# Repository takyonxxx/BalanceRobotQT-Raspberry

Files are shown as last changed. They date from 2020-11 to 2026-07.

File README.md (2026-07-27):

# Balance Robot — Pi 5 + iOS Remote (BLE)

A two-wheeled self-balancing robot. Qt/C++ control application on Raspberry Pi 5, with an iOS BLE remote control featuring a **PID auto-tune (learning) mode** and a **Claude voice assistant** (speak to the robot, Claude drives it).

<p align="center">
    <a href="https://github.com/takyonxxx/BalanceRobotQT-Raspberry/blob/master/remote_ios.jpg">
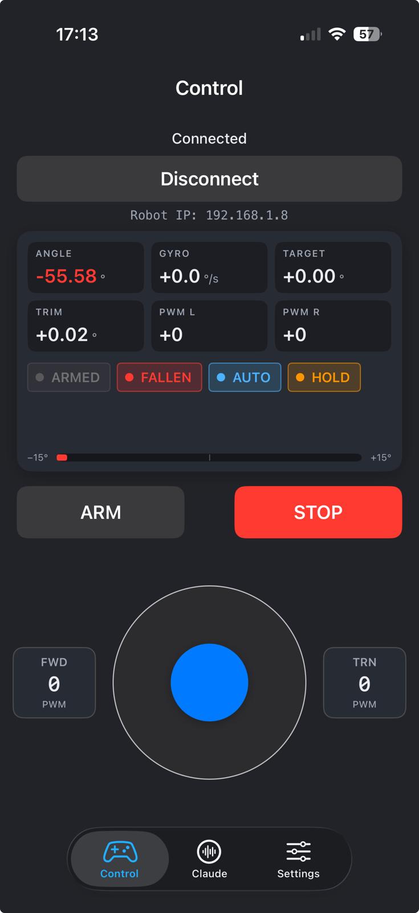
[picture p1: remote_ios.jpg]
iOS Remote
        
    </a>
</p>

## Demo video

See the robot in action: [Balance Robot — YouTube](https://www.youtube.com/watch?v=qpsppoBpccU)

## Architecture

```
iOS Joystick ──BLE GATT──> Pi 5 (Qt/C++) ──> Motor Driver
                              ↑                    ↓
                           MPU6050              Encoders
                          (IMU @ I2C)          (Quadrature)
```

**Control architecture — B-Robot style cascaded PID:**

```
joystick ──> Speed PID ──> target tilt ──> Pitch PID ──> motor PWM
              (outer)                       (inner)
                ↑                              ↑
            encoder vel                  IMU angle + gyro
```

- **Speed PID (outer loop):** Computes the correct body tilt to track the target velocity. When the stick is released, it leans the opposite way to **brake automatically**.
- **Pitch PID (inner loop):** Generates motor PWM to chase the target angle and keep the robot upright.

## Parameters

All parameters can be tuned live from the iOS Settings tab and are persisted to `settings.ini` on the Pi.

### Pitch PID — Balance (inner loop)

| Parameter | Default | Description |
|---|---|---|
| P (Proportional) | 25 | Instant response to angle error. High = stiff correction, oscillation risk. |
| I (Integral) | 40 (0.40 real) | Corrects persistent angle error (gravity bias). |
| D (Derivative) | 0.10 | Angle rate of change — damping. High = reduces swinging. |
| Angle trim (AC) | 0.0° | Manual angle offset. |
| Yaw gain (SD) | 2.0 | Heading correction from encoder difference. |

### Speed PID — Velocity control (outer loop)

| Parameter | Default | Description |
|---|---|---|
| Speed Kp | 0.12 | Instant response to velocity error. High = agile but oscillates. |
| Speed Ki | 0.20 | Integrates velocity error — the workhorse of the Speed PID. |
| Speed Max Tilt | 5° | Maximum tilt angle the Speed PID can request. |
| Speed Max Vel | 3.0 | Target velocity at full stick deflection (encoder ticks/loop). |

### iOS-only

| Parameter | Default | Description |
|---|---|---|
| Forward speed | 180 | Max byte value (0-255) sent for forward/back joystick. |
| Turn speed | 60 | Max byte value sent for left/right joystick. |

## Tuning guide

### For snappier response
1. First raise **Speed Max Vel** (3.0 → 4.0 → 5.0) — increases target velocity ceiling
2. Then raise **Speed Kp** (0.12 → 0.15 → 0.18) — more agile response
3. If still not enough, raise **Speed Max Tilt** (5° → 6° → 7°) — more aggressive acceleration

### Symptoms and fixes
- **Long coast after stick release** → raise Speed Ki (0.20 → 0.30)
- **Oscillating / jittery** → lower Speed Kp
- **Swings back and falls after release** → lower Speed Ki
- **Drifts in place, won't sit still** → raise Pitch Ki
- **High-frequency vibration** → raise Pitch Kd
- **Front-to-back wobble during startup** → lower Pitch Kp

### Reset to Defaults
At the bottom of the iOS Settings tab, the red **"Reset all settings to defaults"** button restores every PID parameter to the Pi-side defaults.

## PID auto-tune — learning mode

Instead of tuning the Pitch PID by hand, the robot can tune itself. The Pi runs a **Twiddle (coordinate-descent) auto-tuner** that evaluates candidate `[Kp, Kd, Ki]` sets live while the robot balances, and commits the best set to `settings.ini` when done.

**How it works:**

1. Each candidate is evaluated for ~9 s (2 s settle + 7 s measure).
2. During measurement each candidate is exercised with a **gentle real maneuver script** through the same command channels the joystick and voice use: 0.8 s forward at command 60/180 then CUT (brake transient measured), 0.8 s backward then cut, 0.5 s left turn at 20/60, 0.5 s right turn, then idle recovery. Long recovery gaps separate the maneuvers. Intensity is tunable in `settings.ini` root: `learnMoveCmd=60`, `learnTurnCmd=20` — lower them if the robot still falls during evals. The cost window includes the moments right after each cut, so the tuner directly rewards "come back to balance as fast as possible after *dur*".
3. Cost = angle-error² + gyro-rate² + PWM² (weighted) → tracking accuracy, oscillation and motor chatter are all penalized together.
4. Twiddle shrinks/grows the search deltas per gain; the run converges typically in 3–6 minutes (hard cap: 40 evaluations, ~7 min with maneuvers).

**Safety & fall recovery:** a fall during an evaluation is detected (maneuver commands are zeroed immediately), that candidate gets infinite cost and gains revert to the best known set. The run then **waits for you**: stand the robot upright, auto-arm kicks in, and learning resumes with a fresh candidate from where it left off — the robot even tells you so ("Beni dik konuma getirirsen öğrenmeye kaldığım yerden devam ederim"). Five falls abort the whole run (best-so-far kept). Touching the joystick restarts only the current candidate's measurement; the tuner's own scripted maneuvers do NOT count as user input.

**How to start it:**

- iOS **Settings tab → "PID LEARNING (AUTO-TUNE)" card → Start**. Live status lines from the Pi (baseline cost, per-evaluation results, best gains found) stream into the card.
- Or by voice, from the **Claude tab**: *"PID öğrenmeyi başlat"* / *"start PID learning"*.

**Ground rules:** run it on a hard, flat floor with ~1 m of clear space around the robot — it wobbles on purpose. The robot must already be able to balance on its own before you start. Only the Pitch PID (inner loop) is optimized; Speed PID stays on the sliders.

## Claude voice assistant (iOS)

The third tab, **Claude**, turns the phone into a voice interface for the robot. Tap the mic, speak (Turkish or English), and Claude answers out loud — and can actually drive the robot through tool calls.

```
Mic ──> SFSpeechRecognizer (tr-TR) ──> Anthropic Messages API ──> tool calls ──> BLE commands
                                              │
                                              └──> reply text ──> AVSpeechSynthesizer (spoken)
```

**Tools Claude can use:**

| Tool | What it does |
|---|---|
| `move_robot` | forward / backward / left / right, speed 10–100 %, duration 0.3–5 s (auto-stops when the duration ends) |
| `stop_robot` | zero all motion commands immediately |
| `set_armed` | ARM / DISARM |
| `start_pid_learning` / `stop_pid_learning` | PID auto-tune control |
| `get_robot_status` | reads live telemetry (angle, PWM, armed / fallen / learning flags) |
| `reset_trim` | zero the trim integrator |

Example voice commands: *"ileri git"*, *"iki saniye sağa dön"*, *"dur"*, *"PID öğrenmeyi başlat"*, *"robot nasıl, denge durumu ne?"*, *"motorları kapat"*.

**Setup — API key only, no username/password:**

**Free offline mode (no API, no cost):** if no API key is entered, the Claude tab automatically falls back to an **on-device keyword parser** (`LocalCommandParser.swift`). All robot voice commands — move, stop, arm/disarm, PID learning, status, trim — work **completely free and offline** (speech recognition itself is Apple's, also free). What you lose without an API key is only the conversational part: free-form questions, multi-step reasoning, and natural phrasing ("take it easy and go a bit forward"). Commands must roughly match the keywords (*ileri, geri, sola, sağa, dur, durum, PID öğrenmeyi başlat, trim sıfırla, motorları kapat* — with optional "*iki saniye*" duration and "*hızlı/yavaş/%60*" speed modifiers).

If you do want full conversational Claude: the assistant talks directly to the Anthropic API. There is **no login, no username, no password anywhere** — the only credential is an **API key** (pay-per-use, separate from any Claude subscription):

1. Create a key at [console.anthropic.com](https://console.anthropic.com) → **API Keys** (the key starts with `sk-ant-`). This is tied to your Anthropic account and billing; the app itself never asks you to sign in.
2. In the app, open the **Claude** tab and tap the **key (🔑) button**, paste the key. It is stored on-device in `UserDefaults` and sent only in the `x-api-key` header of API requests.
3. On first mic use, iOS will ask for **Microphone** and **Speech Recognition** permissions — both must be granted (usage descriptions are already in `Info.plist`).

Default model is `claude-sonnet-4-6` (`AppSettings.claudeModel`). The **speak replies** switch on the tab toggles text-to-speech; typing in the text field works as an alternative to the mic.

**Free cloud alternative — Google Gemini (free quota):** full conversational assistant without paying, using Gemini's free API tier:

1. Go to [aistudio.google.com/apikey](https://aistudio.google.com/apikey), sign in with any Google account and create an API key (starts with `AIza`). **No credit card required** — the free tier gives a daily request quota that is plenty for hobby use.
2. In the app, tap the **key (🔑) button** on the Claude tab → **"Gemini anahtarı gir (ücretsiz)"**, paste the key.
3. Done — the same voice pipeline, tools and robot commands now run through Gemini (`GeminiService.swift`, default model `gemini-2.0-flash`).

Provider priority is automatic: **Claude key → Gemini key → offline parser**. If both keys are set, Claude is used; delete keys from the same 🔑 menu to fall back. If the Gemini free quota runs out for the day (HTTP 429), the app tells you to wait — or just use the offline command mode, which never runs out.

## Direction convention

- **Joystick up** = forward
- **Joystick down** = backward
- **Joystick left/right** = turn
- On the Pi: `cmd > 0` means forward, `cmd < 0` means backward
- Encoder positive direction = robot's forward direction

`ControlViewController.swift:41` has `invertY = false` to enforce this. If your motors are wired in reverse, flip it to `true`.

## BLE protocol — Message IDs

`message.h` (Pi) and `MessageService.swift` (iOS) must match.

```
mHeader        = 0xb0  // Packet header
mWrite         = 0x01  // Write request
mRead          = 0x02  // Read request
mArmed         = 0x03  // ARM robot
mDisArmed      = 0x04  // DISARM robot
mForward       = 0xa0  // Forward command
mBackward      = 0xa1  // Backward command
mLeft          = 0xb0  // Turn left
mRight         = 0xb1  // Turn right
mPP            = 0xc0  // Pitch Kp
mPI            = 0xc1  // Pitch Ki
mPD            = 0xc2  // Pitch Kd
mSpdKp         = 0xc3  // Speed Kp (value/100)
mSpdKi         = 0xc4  // Speed Ki (value/100)
mSpdMaxTilt    = 0xc5  // Speed Max Tilt (raw degrees)
mSpdMaxVel     = 0xc6  // Speed Max Vel (value/10)
mAC            = 0xd0  // Angle trim (value/10)
mSD            = 0xd1  // Yaw gain (value/10)
mData          = 0xe1  // Pi → Phone IP / diagnostics text
mTelemetry     = 0xf0  // Live telemetry stream
mAutoMode      = 0xf1  // Auto-arm on/off
mTrimFine      = 0xf2  // Fine trim
mPositionHold  = 0xf3  // Position hold
mResetTrim     = 0xf4  // Reset trim
mPidLearn      = 0xf5  // PID auto-tune: write 1=start 0=stop, read=state
mPidStatus     = 0xf6  // Pi -> Phone: PID learn status text (UTF-8)
```

> `0xe0` is reserved (formerly `mSpeak` / on-board TTS, removed in the cleanup pass).

Telemetry flags byte (packet byte 12): bit0 = armed, bit1 = fallen, bit2 = auto-mode, bit3 = position-hold, **bit4 = PID learning active**.

## Voice assistant on the Pi — phone-free operation

The robot can also listen and act **entirely on its own**: a USB microphone on the Pi, offline Turkish speech recognition, and the same command/LLM pipeline as the iOS app — working even when the mobile app is closed. Main control lives on the Pi; the phone becomes optional.

```
USB mic ──> arecord ──> Vosk (offline TR STT) ──> intent router
                                                     │
                                     ┌───────────────┴───────────────┐
                                     │ command?                       │ question?
                                     ▼                                ▼
                          local keyword parser              Gemini (free) / Claude API
                          (ileri/geri/dur/PID/durum)        with the same robot tools
                                     │                                │
                                     └────────────┬───────────────────┘
                                                  ▼
                                   RobotControl (atomic, thread-safe)
                                                  +
                                   Piper TTS ────────> speaker
```

**How commands vs questions are separated:** every recognized utterance first goes through the local keyword parser (same vocabulary as the iOS offline mode). If it matches a robot command it executes immediately — offline, free, low latency. Anything that doesn't match is treated as a question and forwarded to the LLM (Gemini free tier or Claude, whichever key is set in `settings.ini`), which can still drive the robot through the same 7 tools. No key set → commands still work, questions get a spoken "komutları söyle" hint.

**Wake word:** by default the robot only reacts to utterances containing "robot" ("robot ileri git"). After the wake word it keeps listening for 10 s so follow-ups don't need it. Set `wakeWord=` (empty) in `settings.ini` to react to everything.

**Language — speak TURKISH to the Pi:** the bundled speech model (`vosk-model-small-tr`) understands **Turkish only**. English keywords exist in the parser for completeness, but the Turkish acoustic model will not transcribe spoken English reliably — so on the Pi, use Turkish. (The iOS app is different: Apple's recognizer handles both TR and EN.) To make the Pi English-speaking instead, download `vosk-model-small-en-us-0.15` and point `voskModelPath` at it.

**Voice command reference (Pi) — complete list.** Say the wake word first — *"robot …"*. After any command a 10-second attention window opens: follow-ups don't need the wake word. Saying just *"robot"* gets *"Evet, dinliyorum"* and opens the window. Word order inside the sentence doesn't matter.

| Amaç | Tetikleyici kelimeler (herhangi biri yeter) | Örnek |
|---|---|---|
| **İleri** | ileri, öne, forward | *"robot ileri git"* |
| **Geri** | geri, arkaya, back | *"robot geri git"* |
| **Sola dön** | sol, sola, left (tam kelime) | *"robot sola dön"* (varsayılan %50, 1 sn) |
| **Sağa dön** | sağ, sağa, right (tam kelime) | *"robot sağa dön"* (varsayılan %50, 1 sn) |
| **Dur** | dur, stop, kes, bekle | *"dur"* (pencere içinde "robot" gerekmez) |
| **Kendini tanıt** | tanıt, tanımla, kimsin, kendini | *"robot kendini tanıt"* — tasarımcısı dahil kısa tanıtım okur |
| **Durum oku** | durum, nasıl, status, telemetri, açı, denge | *"robot durum ne"*, *"robot nasılsın"* |
| **PID öğrenme başlat** | pid/öğren/learn + başlat, başla, start, aç | *"robot PID öğrenmeyi başlat"* |
| **PID öğrenme durdur** | pid/öğren/learn + durdur, bitir, iptal, stop, kapat | *"robot PID öğrenmeyi durdur"* |
| **Trim sıfırla** | trim + sıfırla, resetle, reset, temizle | *"robot trim sıfırla"* |
| **Motorları kapat (disarm)** | disarm, motorları kapat, motoru kapat, devre dışı | *"robot motorları kapat"* |
| **Motorları aç (arm)** | arm, hazırlan, dengele, motorları aç, motoru aç | *"robot motorları aç"* |
| **Serbest soru** (API anahtarı gerekir) | yukarıdakilerle eşleşmeyen her şey | *"robot neden devriliyorsun?"* |

**Hareket komutlarına eklenebilen niteleyiciler** (ileri/geri/sola/sağa ile birlikte, sırası önemsiz):

| Niteleyici | Söyleyiş | Etki |
|---|---|---|
| Hız — kelimeyle | yavaş / nazik → %30 · hızlı → %75 · çok hızlı → %90 · tam gaz / full → %100 | *"robot yavaş ileri git"* |
| Hız — yüzdeyle | "yüzde" + sayı (on…doksan, yüz veya rakam), %10–100 | *"robot yüzde altmış ileri git"* |
| Süre | sayı + "saniye" (yarım, buçuk, bir…on veya rakam), 0.3–8 sn | *"robot üç saniye geri git"* |
| Birleşik | hız + süre aynı cümlede | *"robot yüzde kırk iki saniye sola dön"* |

Varsayılanlar (niteleyici söylenmezse): ileri/geri **%100 / 1.5 sn**, dönüşler **%50 / 1 sn** (`settings.ini` → `moveDefaultPct` / `turnDefaultPct` / `moveDefaultSecs`). Hareket süre sonunda otomatik durur; *"dur"* her an keser.

The rows above are matched **offline by the local parser** — free, instant, no internet. Only free-form questions need an API key.

**New files:** `voiceassistant.cpp/.h` (mic capture, Vosk STT via `dlopen`, intent routing, TTS queue), `llmclient.cpp/.h` (Gemini + Claude REST clients with the tool loop, Qt-native). `libvosk` is loaded at **runtime** — it is *not* a build dependency, so the firmware builds and runs unchanged if voice components aren't installed.

### Setup

```bash
# 1. Audio tools + TTS
sudo apt-get install alsa-utils

# 2. Vosk library (prebuilt aarch64, ~2 MB)
cd /tmp
wget https://github.com/alphacep/vosk-api/releases/download/v0.3.45/vosk-linux-aarch64-0.3.45.zip
unzip vosk-linux-aarch64-0.3.45.zip
sudo cp vosk-linux-aarch64-0.3.45/libvosk.so /usr/local/lib/
sudo ldconfig

# 3. Turkish speech model (~45 MB, runs real-time on one Pi 5 core)
cd ~/BalanceRobotPI
wget https://alphacephei.com/vosk/models/vosk-model-small-tr-0.3.zip
unzip vosk-model-small-tr-0.3.zip

# 4. Microphone: the WEBCAM'S BUILT-IN MIC works - no separate mic needed.
#    The camera streaming service only holds the VIDEO device (v4l2), so the
#    same webcam's audio capture is free to use concurrently.
#    micDevice=auto scans `arecord -l` and picks the USB/webcam mic itself;
#    to check manually:
arecord -l          # e.g. "card 1: Device [USB Audio Device], device 0" -> plughw:1,0
arecord -D plughw:1,0 -f S16_LE -r 16000 -c 1 -d 3 test.wav && aplay test.wav   # 3 s mic test

# 5. settings.ini ([assistant] section, created on first run - voice is
#    ENABLED BY DEFAULT; set enabled=false to turn it off):
#    enabled=true
#    micDevice=auto              ; or plughw:1,0 to pin a specific card
#    voskModelPath=/home/pi/BalanceRobotPI/vosk-model-small-tr-0.3
#    wakeWord=robot
#    geminiApiKey=AIza...        ; optional - free quota, for questions
#    claudeApiKey=               ; optional - takes priority if set
#    piperModel=                 ; optional - path to a Piper .onnx voice (pick a female one, e.g. tr_TR-dfki-medium) for natural TTS
#    moveDefaultPct=100          ; voice move speed %% when not specified (10-100)
#    moveDefaultSecs=1.5         ; voice move duration when not specified (0.5-8 s)
#    turnDefaultPct=50           ; default turn speed %% (100%% turns tip the robot)
#    turnDefaultSecs=1.0         ; default turn duration (fwd/back keep moveDefaultSecs)
#    voiceMaxVel=6.0             ; TEMP speed ceiling for voice fwd/back moves
#                                ; (ticks/loop; joystick keeps its own spdMaxVel;
#                                ;  released when the move stops; 0=disable)
#
# Feeling sluggish even at 100%? The speed cascade is deliberately gentle.
# Three knobs (root section of settings.ini, shared with the joystick):
#    spdTiltSlew=0.04   ; accel ramp, deg/loop (0.02=4°/s gentle, 0.06=12°/s brisk)
#    spdMaxVel=5.0      ; top speed target, encoder ticks/loop (default)
#    spdKi=0.45         ; speed integral (default; spdKp=0.25 for instant response)
# Raise ONE at a time and retest; too much of any can reintroduce tip-overs.

# 6. Restart the app; look for:  VoiceAssistant: listening on plughw:1,0 (wake word: "robot")
```

**Bluetooth speaker (e.g. JBL) for the robot's voice:** replies can play through a BT speaker, managed entirely from `settings.ini`. The stack is **BlueALSA** (not PulseAudio/PipeWire) because the app runs as root and needs a system-level ALSA path.

```bash
# One-time setup
sudo apt-get install bluez-alsa-utils

# Verify the BlueALSA daemon supports playback (a2dp-source):
systemctl status bluealsa    # if OPTIONS lack a2dp-source: edit /etc/default/bluez-alsa
                             # -> OPTIONS="-p a2dp-source"  then: sudo systemctl restart bluealsa

```

**Pairing walkthrough (one-time, from scratch):**

1. Stop the robot app first if it's running (Ctrl+C) — its 30-second auto-connect
   attempts can interfere with pairing.
2. Put the speaker in **pairing mode**: on the JBL Clip 4, with the speaker ON,
   press the **Bluetooth button** (next to power) once — the LED starts
   **blinking blue**. Solid LED = it's connected to another device (e.g. your
   phone): turn that device's Bluetooth off first, then press the BT button.
3. SSH into the Pi and enter the Bluetooth shell — the prompt changes to
   `[bluetooth]#`:

```bash
ssh pi@192.168.1.8
bluetoothctl
```

4. Inside `[bluetooth]#` run, in order (Tab completes the MAC after a few chars):

```
power on
default-agent
scan on                        # wait until "JBL Clip 4" appears with its MAC
pair F8:5C:7D:82:CE:9B         # expect: Pairing successful
trust F8:5C:7D:82:CE:9B        # IMPORTANT - enables automatic reconnection
connect F8:5C:7D:82:CE:9B      # expect: Connection successful + tone from JBL
scan off
quit
```

5. Quick audio test back in the normal shell:

```bash
aplay -D bluealsa:DEV=F8:5C:7D:82:CE:9B,PROFILE=a2dp /usr/share/sounds/alsa/Front_Center.wav
```

**Pairing troubleshooting:**

| Error | Cause | Fix |
|---|---|---|
| `AuthenticationFailed` | Speaker not in pairing mode / connected to your phone | Phone BT off → JBL BT button (blinking blue) → retry `pair` |
| `AlreadyExists` | Stale half-pairing record | `remove F8:5C:7D:82:CE:9B`, then `pair` again |
| `not available` | Dropped from scan list | `scan on`, retry `pair` as soon as it reappears |
| `ConnectionAttemptFailed` | Range/timing | Move JBL closer, press BT button, retry |
| Paired but no sound | Audio path issue, not pairing | Continue with the `bluez-alsa-utils` / `aplay` test above |
| `Couldn't get BlueALSA PCM: PCM not found` + `Device not available: .../sep1/fd0` in `journalctl -u bluealsa` | **PipeWire/WirePlumber grabs the BT stream** before BlueALSA (default on RPi OS Bookworm) | Disable PipeWire's Bluetooth module, then reconnect — see below |

**PipeWire conflict fix (RPi OS Bookworm, one-time):** bluetoothctl reports `Connection successful` yet BlueALSA playback fails, because the desktop audio stack owns the A2DP endpoint. Hand Bluetooth audio to BlueALSA (other audio is unaffected):

```bash
mkdir -p ~/.config/wireplumber/bluetooth.lua.d
echo 'bluez_monitor.enabled = false' > ~/.config/wireplumber/bluetooth.lua.d/80-disable-bluez.lua
systemctl --user restart wireplumber

bluetoothctl disconnect F8:5C:7D:82:CE:9B && sleep 2 && bluetoothctl connect F8:5C:7D:82:CE:9B
aplay -D bluealsa:DEV=F8:5C:7D:82:CE:9B,PROFILE=a2dp /usr/share/sounds/alsa/Front_Center.wav   # should play
```

The change is persistent across reboots. (On headless/Lite images without PipeWire, `systemctl --user` may fail — then a plain disconnect/reconnect usually suffices.)

Pairing is **persistent** (stored under `/var/lib/bluetooth/`): it survives reboots and is never repeated in daily use. Day-to-day you only power the JBL on — the app's auto-connect (every 30 s) does the rest.

Then in `settings.ini` `[assistant]`:

```ini
btSpeakerMac=F8:5C:7D:82:CE:9B   ; default: Türkay's JBL Clip 4; empty = no BT speaker
speakerDevice=                   ; optional ALSA device override; empty = auto
                                 ; (bluealsa:DEV=<MAC>,PROFILE=a2dp built from the MAC)
```

Behavior: on startup the assistant runs `bluetoothctl connect <MAC>` and retries every 30 s, so power-cycling the JBL just works. If a reply fails to play on the BT device (speaker off / out of range), the same sentence is **automatically repeated on the default output** (3.5 mm/HDMI) and reconnection is triggered — the robot never goes silent. Expect ~0.2–0.5 s of extra latency on BT audio; the microphone path (webcam) is unaffected.

**Voice output — Piper (the only TTS engine):** natural offline Turkish voice (`tr_TR-dfki-medium`). Install once; the firmware auto-detects the model file. Without the model+binary, replies are simply not spoken (a log line says so) — everything else keeps working. install [Piper](https://github.com/rhasspy/piper) once; the firmware **auto-detects** the model file and switches to it, no settings change needed:

```bash
# 1. Piper binary (aarch64)
cd /tmp
wget https://github.com/rhasspy/piper/releases/download/2023.11.14-2/piper_linux_aarch64.tar.gz
sudo tar -xzf piper_linux_aarch64.tar.gz -C /opt
sudo ln -s /opt/piper/piper /usr/local/bin/piper

# 2. Turkish female voice model (~60 MB) into the app folder
cd ~/BalanceRobotPI
wget https://huggingface.co/rhasspy/piper-voices/resolve/main/tr/tr_TR/dfki/medium/tr_TR-dfki-medium.onnx
wget https://huggingface.co/rhasspy/piper-voices/resolve/main/tr/tr_TR/dfki/medium/tr_TR-dfki-medium.onnx.json

# 3. Test it
echo "Merhaba, ben denge robotu." | piper -m tr_TR-dfki-medium.onnx --output_raw | \
  aplay -q -r 22050 -f S16_LE -t raw -c 1 -D bluealsa:DEV=F8:5C:7D:82:CE:9B,PROFILE=a2dp
```

Restart the app — replies now use the natural female voice (adds ~0.5 s per sentence on the Pi 5). Reply wording is intentionally SHORT: qualifiers (duration/speed) are spoken back **only if you said them** — *"sola dön"* → *"Sola dönüyorum."*, *"1 saniye sola dön"* → *"Sola dönüyorum, 1 saniye."*

**CPU budget:** the assistant thread runs at low priority; Vosk small uses well under one core. Combined with the camera stream, prefer 640×480 video or disable the camera during PID auto-tune — same guidance as before, the 200 Hz balance loop always has priority.

**Coexistence with the app:** BLE and voice use the same atomic `RobotControl` interface, so both can be active at once. Voice `move` commands auto-stop after their duration; touching the phone joystick simply overrides them.

## Hardware

### Bill of materials

| Part | Specification |
|---|---|
| **Main controller** | Raspberry Pi 5 (Qt/C++ + WiringPi, `wiringPiSetupPhys()`) |
| **IMU** | MPU6050 — 6-axis (3-axis accel + 3-axis gyro), I²C bus 1, address `0x68`. Fused through a Kalman filter to recover pitch angle. |
| **Motor driver** | Waveshare RPi Motor Driver Board — dual H-bridge HAT, **2× NXP MC33886** (one chip per motor) |
| **Drive motors** | 2× 37 mm geared DC motor with Hall quadrature encoder, ~100 RPM @ 4.5 V / ~200 RPM @ 9 V |
| **Battery** | 3S LiPo — 11.1 V nominal (12.6 V full, 9.9 V suggested cut-off), 4000 mAh, 20C+ discharge |
| **Camera (optional)** | Generic UVC USB webcam — MJPEG 1280×720 @ 30 fps, streamed as RTSP H.264 via GStreamer + MediaMTX |
| **Chassis** | 190 mm aluminium balance-bot plate, 3 mm acrylic top, 65 mm × 26 mm rubber tires on electroplated plastic hubs, ~520 g bare |

### Motor driver — Waveshare RPi Motor Driver Board

<p align="center">
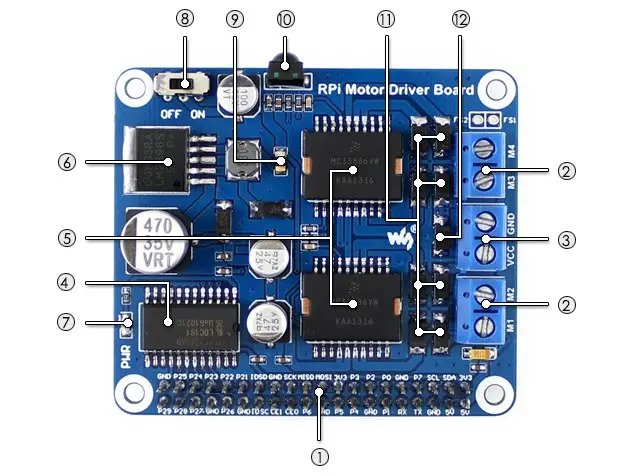
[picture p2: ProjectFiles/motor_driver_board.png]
Waveshare RPi Motor Driver Board — labeled callouts
  
</p>

**Callouts on the photo above:**

| # | Part | Role |
|---|---|---|
| **1** | Raspberry Pi GPIO interface (40-pin header) | Mates with the Pi's header — this is how the six motor-control lines (`PWMR1/PWMR/PWMR2/PWML1/PWML/PWML2`) reach the driver. |
| **2** | Motor screw terminals (M1 A/B, M2 A/B) | Where the two DC motors connect. M1 = right motor, M2 = left motor in this project. |
| **3** | External power input (VIN, GND) | The 3S LiPo (11.1 V) wires land here. 7–40 V accepted. |
| **4** | 74LVC4245AD level-shifter | Voltage translator between the Pi's 3.3 V GPIOs and the H-bridge logic. Acts as a buffer too — protects the Pi. |
| **5** | MC33886 H-bridge × 2 | The actual motor drivers. One chip per motor, up to 5 A each. |
| **6** | LM2596-5.0 5 V regulator | Steps the battery voltage down to 5 V for the Pi. Lets a single battery power the whole robot. |
| **7** | Power indicator LED | Lights when VIN is present and the 5 V rail is healthy. |
| **8** | **Pi power-source switch (OFF / ON)** | Selects who powers the Pi. **OFF** = Pi powered externally (USB-C, the driver is *not* feeding the Pi). **ON** = the driver's 5 V regulator feeds the Pi through the 40-pin header. **For this project, set it to ON** so a single LiPo pack runs both. |
| **9** | 2 A self-recovery (polyfuse) | Resettable fuse on the Pi's 5 V rail. If something shorts, it opens; after it cools down it conducts again. |
| **10** | IR receiver | Onboard infrared receiver. **Unused in this project** — the iOS app talks to the Pi over BLE instead. |
| **11** | Schottky diodes | Protect each H-bridge output from reverse-voltage spikes when the motor's inductive load is switched off. |
| **12** | Supply anti-reverse diode | Protects the whole board if you wire the battery backwards. Don't rely on it as a habit, but it has saved many builds. |

The driver is a HAT that sits on the Pi's 40-pin header. Each of the two **NXP MC33886** H-bridges (#5) drives one motor independently:

| Spec | Value |
|---|---|
| H-bridge IC | 2× NXP MC33886 (one per motor) |
| Power input (VIN) | 7–40 V |
| Output current (per motor) | up to 5 A |
| Onboard 5 V regulator | LM2596-5.0 (#6) — back-feeds the Pi from the same battery when switch #8 is ON |
| Onboard IR receiver | yes (#10) — **unused in this project** (BLE replaces IR) |
| Protections | 2 A resettable fuse on the Pi rail (#9), motor-output reverse-voltage protection (#11), supply reverse-voltage protection (#12), plus the MC33886's own short-circuit / over-current / over-voltage / over-temperature protection |
| Logic interface (per motor) | classic *IN1 / IN2 + ENA PWM-enable* — two direction pins + one PWM enable pin |

> **Before first power-up:** make sure switch **#8 is set to ON** so the driver feeds the Pi. If it's OFF and you've removed the USB-C cable, the Pi simply won't boot — a confusing first symptom when nothing else is wrong.

The Pi drives the H-bridges with **8-bit software PWM** via WiringPi's `softPwm` (`PWM_LIMIT = 255`, `PWM_MIN = 8` deadband). Direction is selected by setting `IN1`/`IN2` to opposite levels; coast = both low; the PWM pin gates the output.

### Drive motors

Each motor is a 6-pin geared DC unit — two pins for the H-bridge winding and four for the Hall quadrature encoder on the rear shaft:

<p align="center">
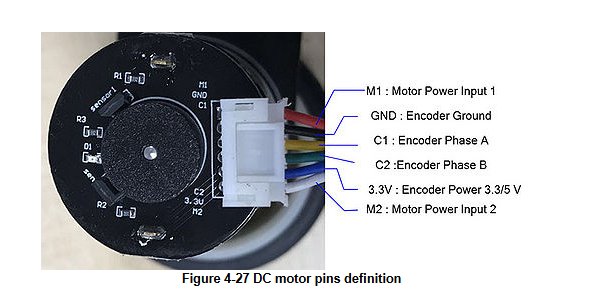
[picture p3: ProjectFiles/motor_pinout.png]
DC motor pin definitions
  
</p>

| Motor pin | Function | Connect to |
|---|---|---|
| `M1` | Motor power input 1 | Motor-driver output A (terminal block) |
| `M2` | Motor power input 2 | Motor-driver output B (terminal block) |
| `GND` | Encoder ground | Pi GND (any GND header pin) |
| `3.3V` | Encoder logic supply (3.3 V or 5 V tolerant) | Pi `+5 V` (header pin 2 or 4) |
| `C1` | Encoder channel A | Pi `SPD_INT_*` (interrupt pin) |
| `C2` | Encoder channel B | Pi `SPD_PUL_*` (direction-sample pin) |

The Pi decodes encoders in **single-edge mode**: rising edge on channel A triggers an ISR, which immediately reads channel B to recover direction and increments or decrements a signed tick counter per wheel. All four encoder inputs use the Pi's internal pull-ups (`PUD_UP`). Tick polarity is runtime-configurable through `encoderInvertL` / `encoderInvertR` in `settings.ini`, so reversed motor wiring can be fixed in software.

### IMU mounting (MPU6050)

The MPU6050 is the single most physically-sensitive component on the robot — where and how you mount it directly affects whether the balance loop can do its job.

<p align="center">
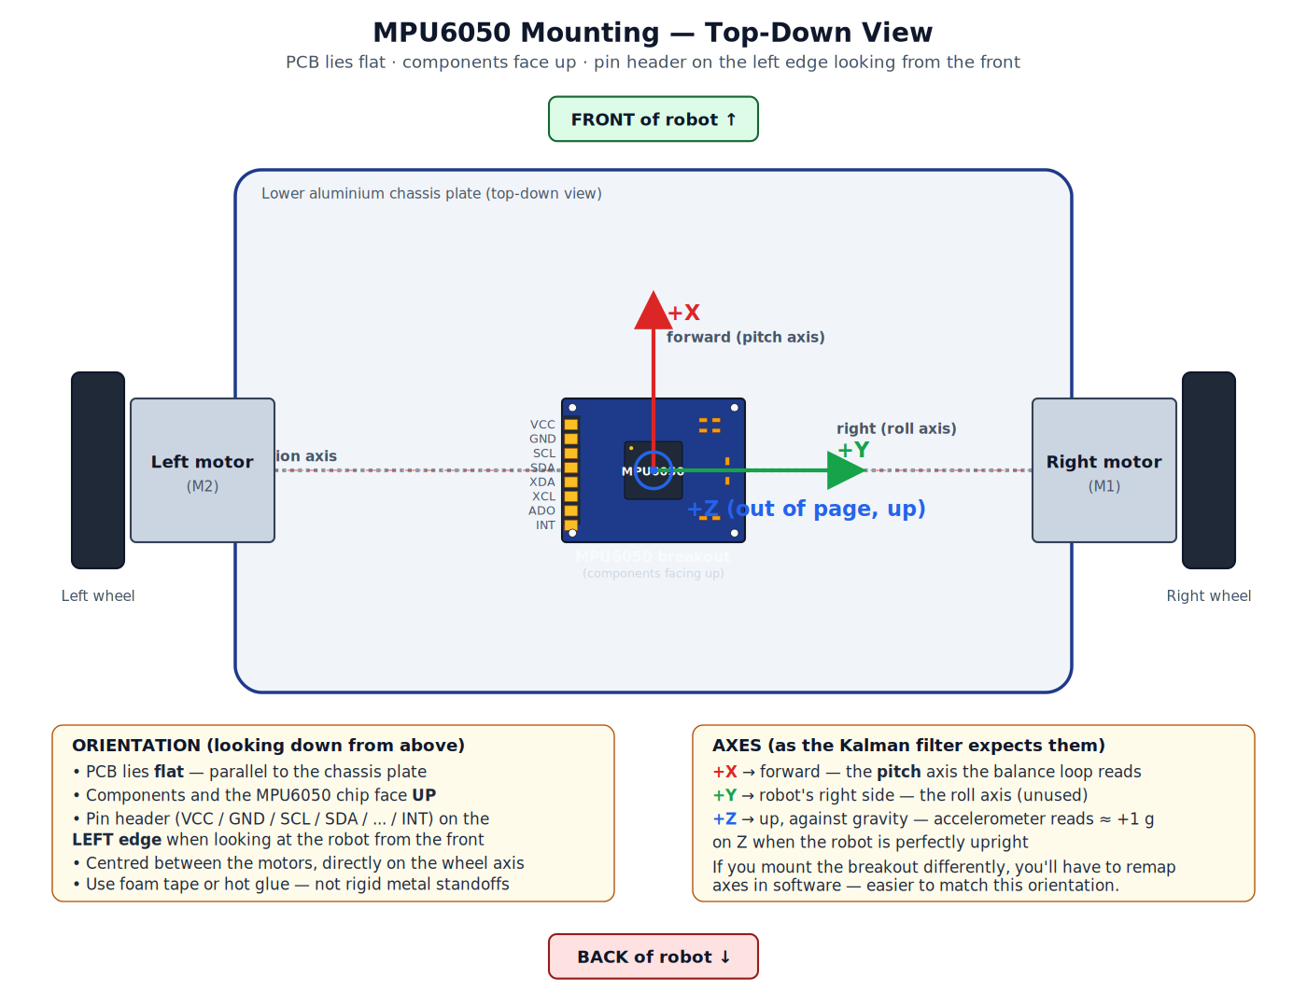
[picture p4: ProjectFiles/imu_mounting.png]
MPU6050 mounting — top-down view of the lower chassis with axes labelled
  
</p>

**Position:** the IMU sits on the **lower chassis plate, centred between the two motors** — i.e. right on the wheel axis line. This is the rotation axis of the robot, so the IMU sees pure pitch when the chassis tilts and isn't contaminated by extra rotational acceleration. Mounting it high up (e.g. next to the Pi on the top deck) makes the gyro pick up swing artefacts and the Kalman filter has to fight that.

**Orientation:** the MPU6050 breakout is mounted **flat (horizontal)**, with the chip and components facing **upwards**. Looking at the robot from the front, the pin header (`VCC / GND / SCL / SDA / XDA / XCL / ADO / INT`) is on the **left edge** of the breakout. This orientation puts:

- IMU **Z axis** → up (against gravity) — accelerometer reads ≈ +1 g on Z when level
- IMU **X axis** → forward (along the direction of travel) — this is the *pitch* axis the Kalman filter reads
- IMU **Y axis** → sideways (roll axis, unused by the balance loop)

If you mount the breakout in a different orientation, you'll need to either remap axes in software or live with `accelAngle` reading garbage. The Kalman code in `robotcontrol.cpp` assumes this exact orientation — easiest to just copy it.

**Wiring:** four wires up to the Pi's 40-pin header — `VCC → pin 2 (+5V)`, `GND → pin 6`, `SDA → pin 3`, `SCL → pin 5`. The breakout's onboard 3.3 V regulator + level shifter accept 5 V on VCC, so feeding from the Pi's 5 V rail is fine and gives a stronger signal than 3.3 V.

**Mechanical tip:** double-sided foam tape works well and adds a tiny bit of mechanical damping (motor vibration → IMU noise). Hot glue is fine too. Don't bolt it rigidly to the chassis with metal standoffs — the gyro picks up every motor whine that way.

### Chassis

<p align="center">
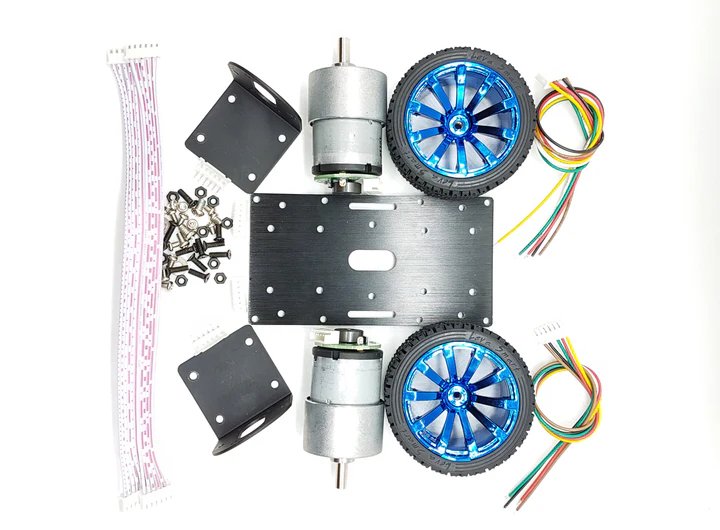
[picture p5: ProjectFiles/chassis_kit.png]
Balance robot chassis kit
  
</p>

Standard self-balancing kit: 190 mm CNC'd aluminium baseplate, motor mounting brackets, two 65 mm wheels with rubber tread, M3 hardware bag, and the encoder/motor wiring harness shown on the right. The Waveshare driver and the Pi stack on top.

**Two-deck layout.** In a finished build the chassis ends up as two stacked plates joined by **brass M3 standoffs** (typically 40–60 mm tall):

- **Lower plate** — motors + brackets at each end, MPU6050 in the centre (between the wheel axes), LiPo battery, power switch, XT60 connector
- **Upper plate** — Pi 5 with the Waveshare driver HAT mounted on top, plus an optional USB camera

Encoder and motor wires route up from the lower plate through the standoff gaps to the Pi/driver above. The two-deck arrangement keeps the heavy battery low (good for the centre of mass) while putting the brains, status LEDs and camera up top where they're accessible.

#### Baseplate dimensions

The dimensioned drawing below is provided so you can design a custom PCB or laser-cut a top deck that fits the standard hole pattern. All dimensions are in millimetres; the plate is **119 mm wide × 64 mm deep** with 22× Ø3.2 mm mounting holes and rounded corners (R5 / R1.6).

<p align="center">
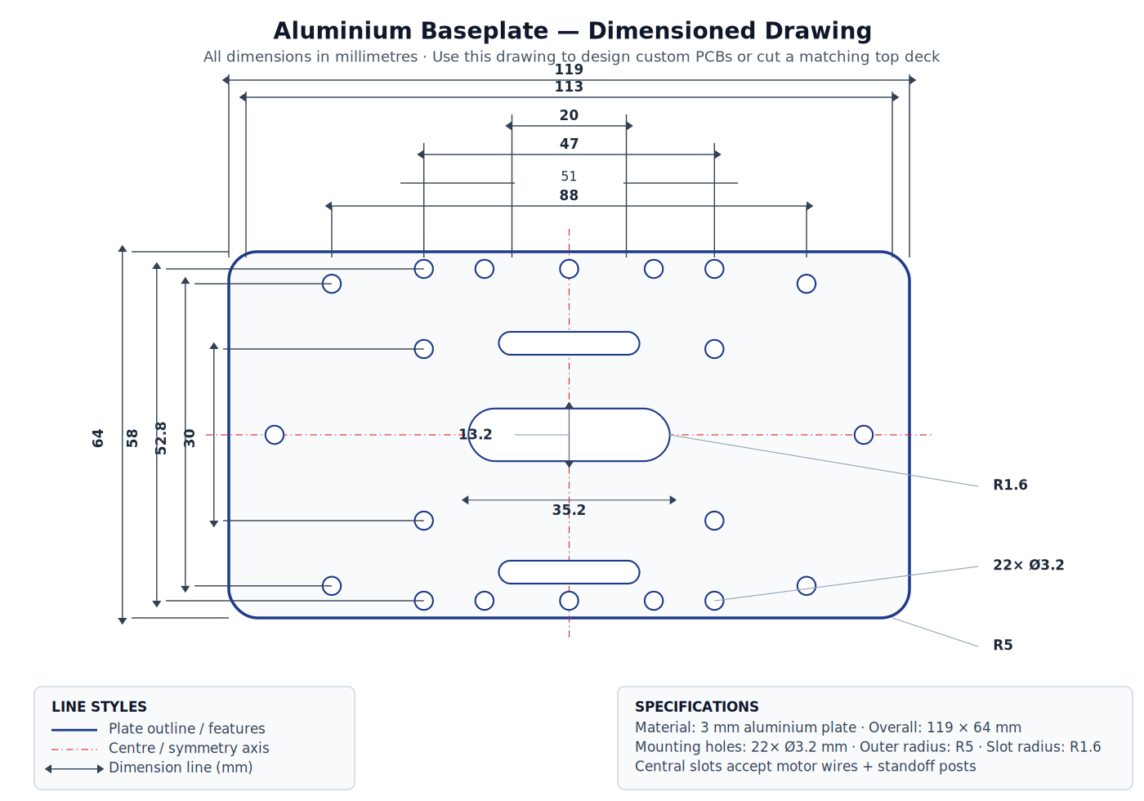
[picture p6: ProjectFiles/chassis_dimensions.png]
Balance robot baseplate — dimensioned drawing
  
</p>

#### 3D-printable parts (STL)

The `ProjectFiles/` folder ships with STL meshes for the printable upper structure of the robot. Slice them in your slicer of choice (Cura, PrusaSlicer, etc.). Recommended print settings: PLA, 0.2 mm layer height, 20% infill, supports off (the parts are designed to print flat without overhangs).

| File | What it is |
|---|---|
| [`Robot_chasis_bottom.stl`](ProjectFiles/Robot_chasis_bottom.stl) | Printable lower chassis plate — alternative to the aluminium baseplate if you want a fully printed build. |
| [`Robot_chasis_top.stl`](ProjectFiles/Robot_chasis_top.stl) | Upper deck that bolts onto the standoffs above the Pi + driver stack. |
| [`Robot_safe_top.stl`](ProjectFiles/Robot_safe_top.stl) | Reinforced top cover variant with extra wall thickness — use it if you expect frequent falls during PID tuning. |
| [`Robot_mask.stl`](ProjectFiles/Robot_mask.stl) | Decorative front mask / face plate. Large mesh (~27 MB), purely aesthetic. |

Also previously in `ProjectFiles/`: `Raspberry_Pi_Model_B.STL`, `Robot_chasis_bottom_with_mpu6050.stl`, `Robot_chasis_top_for_raspberry.stl`, `Robot_chasis_top_single_for_raspberry.stl`, `Robot_chasis_top_with_raspberry.stl`, `Robot_safe_top_for_raspberry.stl`, plus the FreeCAD source files `robot_safe.FCStd` and `robot_top.FCStd` if you want to modify them.

### Power system

The robot runs on a single **3S LiPo battery — 11.1 V nominal**. The Waveshare driver's `VIN` input accepts 7–40 V, so 3S is comfortably within range. A single pack powers everything:

```
3S LiPo (11.1 V) ──> Power switch ──> Driver VIN ──> MC33886 H-bridges ──> motors (full 11.1 V)
                                          │
                                          └──> Onboard 5 V regulator ──> Raspberry Pi 5 (via the HAT)
                                                                          │
                                                                          └──> +5 V rail ──> MPU6050 + encoder PCBs
```

| Spec | Value |
|---|---|
| Battery | 3S LiPo — 3 cells in series |
| Nominal voltage | 11.1 V (3 × 3.7 V) |
| Fully charged | 12.6 V (3 × 4.20 V) |
| Suggested cut-off | ~9.9 V (3 × 3.30 V) — below this, balancing degrades and cells age fast |
| Capacity | 4000 mAh (≈60–90 min runtime depending on motor load) |
| Discharge rating | 20C or higher recommended — peak current can hit 10 A momentarily during a hard correction |
| Connector | XT60 or XT30 to the driver's VIN terminal block (XT60 preferred for >20 A continuous) |
| Inline switch | A latching power switch is wired between the battery's + lead and the driver's VIN. Lets you cut power without unplugging the LiPo every time. |

**Safety notes:**

- **LiPo packs are fire hazards if mistreated.** Always charge in a LiPo-safe bag, never leave a charging pack unattended, and never discharge any cell below 3.0 V.
- A small **inline voltage alarm** that buzzes below 3.3 V/cell is cheap insurance — the Pi has no battery monitoring on its own.
- **Polarity matters.** The driver has reverse-voltage protection on the supply input, but the protection has its limits; double-check polarity before plugging in a freshly-charged pack.
- When the pack voltage drops below ~9.5 V, you'll notice the robot can no longer balance under hard corrections (PWM saturates). That's your cue to land it and swap packs.

### Onboard camera (optional)

The robot can carry a USB webcam that publishes a live RTSP stream — useful for FPV-style remote driving or for tuning the PIDs from a distance. The stream is **independent of the balance control loop** (it runs in its own systemd service) so you can disable it at any time without touching the balancing code.

**Stack:**

```
USB UVC webcam ──> /dev/video0 ──> GStreamer (decode → H.264 encode) ──> MediaMTX ──> RTSP clients
                                                                            (8554/tcp)
```

| Component | Role |
|---|---|
| Any generic UVC webcam | Source. Tested with a "GENERAL WEBCAM" branded MJPEG 1080p USB cam on `/dev/video0`. |
| **GStreamer** (`gst-launch-1.0`) | Pulls MJPEG frames from the camera, decodes to raw, re-encodes to H.264 with `x264enc`, pushes to MediaMTX over `rtspclientsink`. Runs as `webcam-stream.service`. |
| **MediaMTX** | Lightweight RTSP/RTMP/HLS server. Receives the push on `rtsp://localhost:8554/webcam` and re-serves it on the network. Runs as `mediamtx.service`. |

**Stream URL once running:**

```
rtsp://<pi-ip>:8554/webcam

# Current setup (Pi at 192.168.1.8) - copy-paste ready:
rtsp://192.168.1.8:8554/webcam
```

**Performance tuning — why 720p, not 1080p:** software H.264 encoding at 1080p30 uses 2–3 cores on the Pi 5 and competes with the Pitch PID loop, which can introduce balance jitter. The recommended pipeline uses `1280×720 @ 30 fps`, `bitrate=1000 kbps`, `speed-preset=ultrafast`, `threads=2` — this keeps two cores free for `BalanceRobotPI` and stays under ~120% total CPU for the camera service. If you don't need the camera, just `sudo systemctl disable --now webcam-stream mediamtx` and reclaim the CPU.

### Raspberry Pi pin reference

Pin numbering in `constants.h` follows the **40-pin physical header** (because `robotcontrol.cpp` calls `wiringPiSetupPhys()`) — *not* BCM or wiringPi-logical numbering. Use this header diagram when wiring:

<p align="center">
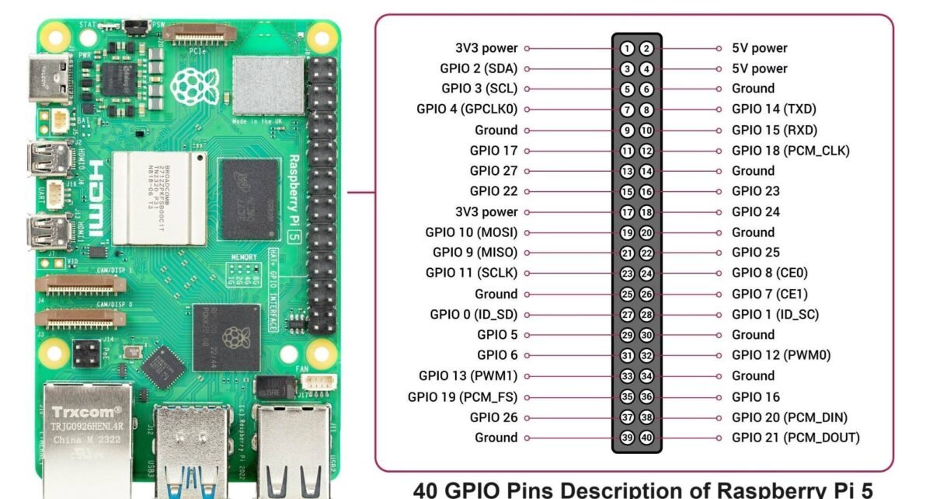
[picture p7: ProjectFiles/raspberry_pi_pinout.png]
Raspberry Pi 40-pin header — physical pin numbering
  
</p>

Motor-driver lines (left motor uses `PWML1`/`PWML2` for direction and `PWML` for PWM enable; right motor mirrored):

```
PWMR1 = pin 31   // Right motor IN1 (direction)
PWMR2 = pin 33   // Right motor IN2 (direction)
PWMR  = pin 32   // Right motor ENA (PWM enable, 0–255)
PWML1 = pin 38   // Left  motor IN1 (direction)
PWML2 = pin 40   // Left  motor IN2 (direction)
PWML  = pin 37   // Left  motor ENA (PWM enable, 0–255)
```

Encoders:

```
SPD_INT_L = pin 16   // Left  encoder channel A (interrupt)   ← motor C1
SPD_PUL_L = pin 12   // Left  encoder channel B (direction)   ← motor C2
SPD_INT_R = pin 18   // Right encoder channel A (interrupt)   ← motor C1
SPD_PUL_R = pin 22   // Right encoder channel B (direction)   ← motor C2
```

> **Note.** In older versions of `constants.h`, the inline comments next to the encoder `#define`s (e.g. `//interrupt R Phys:16`, `//Phys:22`) contradicted the symbolic names and were leftover copy-paste artefacts. The cleaned-up `constants.h` shipped with this project no longer has them — the pin numbers themselves were always correct and consistent end-to-end (`SPD_INT_L = 16` → triggers `encLeftISR` → increments `encLeftTicks_` → drives `encL_eff` → feeds the left-wheel PID).

I²C (MPU6050): SDA on header pin 3, SCL on header pin 5 (`/dev/i2c-1`, addr `0x68`).

### How the 6 motor-drive pins control the H-bridges

Each MC33886 H-bridge needs **3 wires** from the Pi: two direction bits (`IN1` / `IN2`) and one PWM enable (`ENA`). The direction bits pick *which way* the motor spins, and the PWM duty cycle on the enable pin picks *how fast*. With two motors, the Pi spends 6 GPIOs total on motor control — exactly the 6 listed in the `MOTOR DRIVE OUTPUTS` section above.

H-bridge truth table per motor:

| IN1 | IN2 | ENA (PWM) | Result |
|-----|-----|---|---|
| LOW | LOW | x | Coast (motor free-wheels) |
| HIGH | LOW | 0–255 | Forward, speed ∝ duty cycle |
| LOW | HIGH | 0–255 | Reverse, speed ∝ duty cycle |
| HIGH | HIGH | x | Brake (both motor terminals shorted) |

Pin-to-function mapping:

| Side | Pi pin | Name | Role on the H-bridge | Wire color in diagram |
|---|---|---|---|---|
| Right motor | Pin 31 | `PWMR1` | IN1 — direction bit 1 | 🔵 blue (direction) |
| Right motor | Pin 32 | `PWMR`  | ENA — PWM enable (speed) | 🟠 orange (PWM) |
| Right motor | Pin 33 | `PWMR2` | IN2 — direction bit 2 | 🔵 blue (direction) |
| Left motor  | Pin 37 | `PWML`  | ENA — PWM enable (speed) | 🟠 orange (PWM) |
| Left motor  | Pin 38 | `PWML1` | IN1 — direction bit 1 | 🔵 blue (direction) |
| Left motor  | Pin 40 | `PWML2` | IN2 — direction bit 2 | 🔵 blue (direction) |

The Pitch PID produces a signed 16-bit PWM command in the range `−255 … +255` for each wheel. `applyMotors(int pwmL, int pwmR)` in `robotcontrol.cpp` converts that signed value into the right combination of direction bits + PWM duty cycle:

```cpp
// Right motor — positive pwmR means forward
if (pwmR > 0) {
    digitalWrite(PWMR1, HIGH);   // pin 31
    digitalWrite(PWMR2, LOW);    // pin 33
    softPwmWrite (PWMR, pwmR);   // pin 32 — duty 0..255
}
else if (pwmR < 0) {             // negative → reverse
    digitalWrite(PWMR1, LOW);
    digitalWrite(PWMR2, HIGH);
    softPwmWrite (PWMR, -pwmR);
}
else {                           // zero → coast
    digitalWrite(PWMR1, LOW);
    digitalWrite(PWMR2, LOW);
    softPwmWrite (PWMR, 0);
}

// Left motor — IN1/IN2 are SWAPPED (motor is mirror-mounted)
if (pwmL > 0) {
    digitalWrite(PWML1, LOW);    // pin 38  ← note swap
    digitalWrite(PWML2, HIGH);   // pin 40  ← note swap
    softPwmWrite (PWML, pwmL);   // pin 37
}
// ...same pattern for pwmL < 0 and pwmL == 0
```

**Why the left motor's IN1/IN2 are swapped:** the two motors are bolted into the chassis facing each other (mirror-mounted), so "wheel rotates forward" corresponds to *opposite* shaft directions on the two motors. Instead of rewiring the M1/M2 power leads, the code flips the polarity in software so that a positive PWM on either side means "robot moves forward" at the algorithm level. The Speed PID never has to know that the motors are mirror-mounted.

**Why these specific pin numbers (31, 32, 33, 37, 38, 40 — with gaps):** the gaps (34, 35, 36, 39) are header pins reserved for GND or for GPIOs used elsewhere in the project, so the firmware picks the closest run of physical pins that are all free for general output. Because `wiringPiSetupPhys()` is used, the numbers in `constants.h` are exactly what's printed on a Pi pinout diagram — no BCM ↔ wiringPi translation needed.

The whole 6-pin block is rewritten once per Pitch PID tick (~1 kHz), and **this is where the inner balance loop physically closes** — every other layer (Speed PID, joystick, BLE) ultimately just changes the `pwmL` / `pwmR` numbers that land here.

### Wiring diagram

End-to-end map of every connection that `constants.h` and `robotcontrol.cpp` actually drive. Wire colors: **red** +5 V, **black** GND, **purple** I²C, **blue** H-bridge direction, **orange** PWM enable, **green** encoder A/B.

<p align="center">
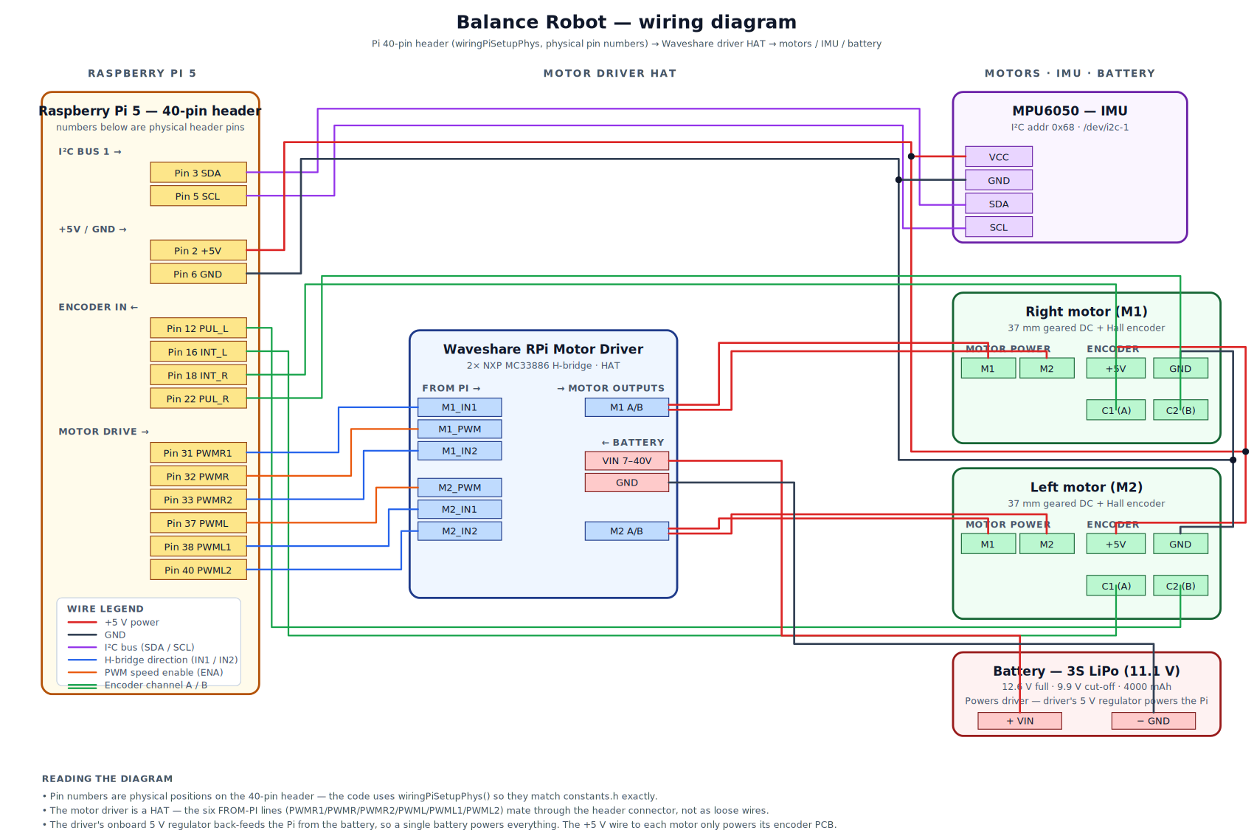
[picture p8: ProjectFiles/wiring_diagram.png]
Balance Robot wiring diagram — Pi 40-pin header to motor driver to motors
  
</p>

A few code-side details worth knowing when wiring:

- `applyMotors()` in `robotcontrol.cpp` **deliberately swaps IN1/IN2 polarity for the left motor**, because the left motor is bolted in mirrored. Positive `pwmR` drives `PWMR1` high; positive `pwmL` drives `PWML2` high.
- If a motor spins backwards, prefer flipping `encoderInvertL` / `encoderInvertR` in `settings.ini` over rewiring — the encoder direction must match the motor direction for the Speed PID to work.
- The motor PCB's encoder rail is labelled `3.3V` but accepts 5 V (the Hall output pulls up to whatever you supply). Feeding it from the Pi's 5 V keeps the encoder signal strong, and the Pi's 3.3 V GPIOs still read it cleanly thanks to the internal pull-ups.

## Installation

### Pi 5

The Pi-side app links against Qt6 (Core / Bluetooth / Network), libi2c, and WiringPi for GPIO + software PWM. Raspberry Pi OS Bookworm (the current Pi 5 default) ships Qt6 in apt — use `qmake6` to build. WiringPi is no longer in the Debian / Raspberry Pi OS repositories, so it must be built from the maintained fork.

```bash
# --- 1. System update ---
sudo apt-get update

# --- 2. Qt6 (Bluetooth + Network are the only required modules) ---
sudo apt-get install qmake6 \
                     qt6-base-dev \
                     qt6-connectivity-dev \
                     libqt6bluetooth6 \
                     libqt6network6

# --- 3. I²C (MPU6050) ---
sudo apt-get install libi2c-dev

# --- 4. WiringPi — must be built from source (no longer in apt) ---
git clone https://github.com/WiringPi/WiringPi.git
cd WiringPi
sudo ./build
cd ..

# --- 5. Enable I²C on the Pi ---
sudo raspi-config       # Interface Options → I2C → Enable, then reboot

# --- 6. Copy the project to the Pi (from your dev machine) ---
# On Windows: note the colon ":" — without it scp copies to a local folder!
#   scp -r BalanceRobotPI pi@<pi-ip>:/home/pi/
# On macOS / Linux: same syntax
#   scp -r BalanceRobotPI pi@<pi-ip>:~/

# --- 7. Build the application (on the Pi) ---
cd ~/BalanceRobotPI
qmake6 BalanceRobotPI.pro
make -j4

# --- 8. Run (sudo is required: WiringPi needs /dev/mem and the BLE GATT
#         server needs to register on the system Bluetooth bus) ---
sudo ./BalanceRobotPI
```

After the first run, parameters tuned from the iOS app are persisted to `settings.ini` next to the binary — keep an eye on it the first time you tune the PIDs.

> **If you're on an older Pi OS with only Qt5**, replace step 2 with
> `sudo apt-get install qtconnectivity5-dev libqt5bluetooth5 libqt5bluetooth5-bin`,
> use `qmake` (not `qmake6`) in step 7, and Qt's classes will resolve to Qt5 headers automatically.

### iOS

1. Extract `BalanceRobotRemote_IOS.zip`
2. Open `RobotControlBLE.xcodeproj` in Xcode
3. Update the bundle identifier with your developer account
4. Build & Run to the device
5. (Optional) For full conversational Claude: get an API key from [console.anthropic.com](https://console.anthropic.com), enter it via the key button on the **Claude** tab, and grant the microphone + speech recognition permission prompts on first use. No username/password is needed anywhere — the API key is the only credential. **Without a key, voice robot commands still work for free** via the built-in offline parser — and for free conversational AI, a Gemini key from [aistudio.google.com/apikey](https://aistudio.google.com/apikey) works too (free quota, no credit card).

### Auto-start on boot (Pi systemd)

`/lib/systemd/system/balancerobot.service`:

```ini
[Unit]
Description=Balance Robot Service
After=multi-user.target

[Service]
Type=idle
WorkingDirectory=/home/pi/BalanceRobotPI
ExecStart=/home/pi/BalanceRobotPI/BalanceRobotPI

[Install]
WantedBy=multi-user.target
```

```bash
sudo systemctl enable balancerobot.service
sudo systemctl start balancerobot.service
```

### Camera streaming (optional)

If your build has a USB webcam mounted on the chassis, set up two services on the Pi — **MediaMTX** (the RTSP server) and **webcam-stream** (the GStreamer pipeline that pushes camera frames into it).

#### 1. Install GStreamer

```bash
sudo apt-get install gstreamer1.0-tools \
                     gstreamer1.0-plugins-base \
                     gstreamer1.0-plugins-good \
                     gstreamer1.0-plugins-bad \
                     gstreamer1.0-plugins-ugly \
                     gstreamer1.0-libav \
                     v4l-utils
```

#### 2. Install MediaMTX

MediaMTX is a single static binary — download the latest aarch64 release for the Pi 5:

```bash
cd /tmp
LATEST=$(curl -s https://api.github.com/repos/bluenviron/mediamtx/releases/latest | grep tag_name | cut -d '"' -f 4)
wget "https://github.com/bluenviron/mediamtx/releases/download/${LATEST}/mediamtx_${LATEST}_linux_arm64.tar.gz"
tar -xzf "mediamtx_${LATEST}_linux_arm64.tar.gz"
sudo mv mediamtx /usr/local/bin/
sudo mkdir -p /etc/mediamtx
sudo mv mediamtx.yml /etc/mediamtx/mediamtx.yml
```

Create the systemd unit `/etc/systemd/system/mediamtx.service`:

```bash
sudo tee /etc/systemd/system/mediamtx.service > /dev/null << 'EOF'
[Unit]
Description=MediaMTX RTSP Server
After=network.target

[Service]
Type=simple
ExecStart=/usr/local/bin/mediamtx /etc/mediamtx/mediamtx.yml
Restart=on-failure
RestartSec=5

[Install]
WantedBy=multi-user.target
EOF
```

#### 3. Verify the camera is detected

Plug the USB webcam in, then:

```bash
v4l2-ctl --list-devices
v4l2-ctl --device=/dev/video0 --list-formats-ext
```

You should see your webcam under a `/dev/video0` (and usually a sibling `/dev/video1`). Confirm it supports `MJPG @ 1280×720 @ 30fps` — if not, adjust the pipeline below to a resolution your camera advertises.

#### 4. Install the GStreamer push service

```bash
sudo tee /etc/systemd/system/webcam-stream.service > /dev/null << 'EOF'
[Unit]
Description=Webcam RTSP Streaming Service
After=network.target mediamtx.service
Requires=mediamtx.service

[Service]
Type=simple
User=pi
WorkingDirectory=/home/pi
ExecStart=/usr/bin/gst-launch-1.0 -v \
  v4l2src device=/dev/video0 ! \
  image/jpeg,width=1280,height=720,framerate=30/1 ! \
  jpegdec ! \
  videoconvert ! \
  x264enc tune=zerolatency bitrate=1000 speed-preset=ultrafast threads=2 key-int-max=30 ! \
  h264parse ! \
  rtspclientsink location=rtsp://localhost:8554/webcam
Restart=on-failure
RestartSec=10
StandardOutput=journal
StandardError=journal

[Install]
WantedBy=multi-user.target
EOF
```

> If you prefer to edit either service later, use `sudo nano /etc/systemd/system/<name>.service` — do **not** use `systemctl edit --full`, which insists on saving to a `.save` file and confuses the unit.

#### 5. Enable and start both services

```bash
sudo systemctl daemon-reload
sudo systemctl enable --now mediamtx.service webcam-stream.service
```

#### 6. Verify

```bash
systemctl status mediamtx --no-pager       | head -10
systemctl status webcam-stream --no-pager  | head -10
```

Both should show `active (running)`. If `webcam-stream` shows `activating (auto-restart)`, look at `journalctl -u webcam-stream -n 50 --no-pager` for the underlying error (camera unplugged, wrong resolution, GStreamer plugin missing, etc.).

#### 7. View the stream

From any device on the same network:

| Client | How |
|---|---|
| **VLC** (macOS / Windows / Linux) | `File → Open Network → rtsp://<pi-ip>:8554/webcam` |
| **VLC for Mobile** (iOS / Android) | `+ → Open Network Stream → rtsp://<pi-ip>:8554/webcam` |
| **ffplay** (CLI) | `ffplay -fflags nobuffer rtsp://<pi-ip>:8554/webcam` |
| **On the Pi itself** | `ffplay rtsp://localhost:8554/webcam` |

Typical end-to-end latency over local Wi-Fi is 300–500 ms with this pipeline — acceptable for FPV driving and PID tuning.

#### Quick on/off

If you ever want to disable the camera (e.g. to free up CPU during aggressive PID tuning), without uninstalling anything:

```bash
sudo systemctl stop    webcam-stream mediamtx
sudo systemctl disable webcam-stream mediamtx   # don't auto-start on boot
```

Re-enable later with `sudo systemctl enable --now webcam-stream mediamtx`.

## File layout

```
BalanceRobotPI/                 # Pi side (Qt/C++)
├── main.cpp                    # Entry point, signal handling
├── balancerobot.cpp/.h         # BLE command handler, top-level orchestration
├── robotcontrol.cpp/.h         # Main control loop (PID, ISRs, motor I/O)
├── pid.cpp/.h                  # Pitch PID
├── kalman.h                    # Header-only Kalman fusion (TKJ Electronics)
├── mpu6050.cpp/.h              # IMU driver
├── i2cdev.cpp/.h               # I²C transport for the MPU6050
├── gattserver.cpp/.h           # BLE GATT server
├── message.cpp/.h              # BLE wire-format pack / parse
├── pidautotuner.cpp/.h         # Twiddle PID auto-tuner (learning mode)
├── voiceassistant.cpp/.h       # Phone-free voice assistant (mic + Vosk + TTS)
├── llmclient.cpp/.h            # Gemini/Claude REST client with robot tools (Qt)
├── constants.h                 # Pin definitions + small helpers
├── BalanceRobotPI.pro          # qmake project
└── settings.ini                # Runtime-persisted parameters (created on first run)

BalanceRobotRemote_IOS/         # iOS side (Swift)
└── RobotControlBLE/
    ├── AppDelegate.swift
    ├── ControlViewController.swift   # Main screen (joystick + telemetry)
    ├── SettingsViewController.swift  # Settings tab (PID sliders)
    ├── JoystickView.swift            # Joystick widget
    ├── MessageService.swift          # BLE message IDs
    ├── AppSettings.swift             # UserDefaults wrapper (incl. Claude API key/model)
    ├── Assistant/
    │   ├── AssistantViewController.swift # Claude tab (chat UI, mic, TTS)
    │   ├── ClaudeService.swift           # Anthropic Messages API client + tool loop
    │   ├── LocalCommandParser.swift      # FREE offline keyword command mode (no API)
    │   ├── GeminiService.swift           # FREE-quota Google Gemini client + tool loop
    │   ├── RobotCommandExecutor.swift    # Claude tool calls -> BLE robot commands
    │   └── SpeechRecognizer.swift        # AVAudioEngine + SFSpeechRecognizer
    └── Ble/
        ├── BluetoothService.swift        # CoreBluetooth wrapper
        └── BluetoothEventsHandler.swift  # Telemetry / notification parsing
```

## Runtime flow

1. Pi boots → `settings.ini` is loaded → BLE starts advertising
2. iOS connects → Settings tab requests current parameters from Pi
3. Robot held upright → IMU detects upright pose → if `Auto-arm` is enabled, it automatically ARMs
4. Pitch PID begins balancing; Speed PID requests a tilt based on joystick input
5. If fall is detected (>40°) → DISARM, motors stop
6. When held upright again, it auto-restarts

## First boot checklist

Before strapping the robot to a LiPo and watching it dance across the floor, run through this list with the chassis sitting on a table (motors free to spin but the robot itself supported so it can't fall).

### 1. I²C and the IMU

With the Pi powered (USB-C is fine for this — driver doesn't need to be on yet):

```bash
sudo apt-get install i2c-tools   # if not installed
sudo i2cdetect -y 1
```

You should see a device at address `68`:

```
     0  1  2  3  4  5  6  7  8  9  a  b  c  d  e  f
00:                         -- -- -- -- -- -- -- --
...
60: -- -- -- -- -- -- -- -- 68 -- -- -- -- -- -- --
70: -- -- -- -- -- -- -- --
```

**If `68` is missing:**
- I²C is not enabled — run `sudo raspi-config` → Interface Options → I2C → Enable, then reboot
- Wiring is wrong — check VCC/GND/SDA/SCL on header pins 2/6/3/5
- The breakout is dead — try another MPU6050

### 2. Bluetooth

```bash
systemctl status bluetooth        # should be "active (running)"
bluetoothctl list                 # at least one controller, "powered: yes"
hciconfig                         # hci0 should be "UP RUNNING"
```

**If the controller is `DOWN`:** `sudo hciconfig hci0 up` or `sudo systemctl restart bluetooth`.

### 3. Driver power switch

On the Waveshare driver, the **OFF/ON switch (callout #8)** decides who powers the Pi. For battery operation, set it to **ON** so the driver's 5 V regulator feeds the Pi from the LiPo. Forget this and the Pi will refuse to boot the moment you unplug USB-C.

### 4. First app launch (with motors disconnected)

Disconnect the motor wires from the driver's screw terminals for this test — we just want to see the app boot cleanly without anything moving.

```bash
cd ~/BalanceRobotPI
sudo ./BalanceRobotPI
```

Look for these lines on stdout / journal:

```
WiringPi ready (encoder ISRs enabled)
RobotControl ready. Kp= 29.2 Ki= 64 Kd= 0.103 trim= 0
Local IP: 192.168.x.x MAC: xx:xx:xx:xx:xx:xx
GattServer advertising as "BalanceRobot"
```

If you see *"wiringPiSetupPhys failed"* → you forgot `sudo` (WiringPi needs `/dev/mem`).

If you see *"Failed to register left/right encoder ISR"* → another process is holding `/sys/class/gpio` — usually a leftover instance, kill it with `sudo pkill BalanceRobotPI`.

### 5. Gyro bias calibration

In the first few seconds after `BalanceRobotPI` starts, **before** the BLE server begins advertising, the code runs an automatic gyro bias calibration. The IMU is sampled 400 times at 5 ms intervals (~2 s per attempt, up to 3 attempts with 1 s pause between) and the mean is stored as the bias to subtract from every subsequent reading. **If the robot moves at all during this window, calibration fails and balance accuracy suffers.**

The acceptance thresholds in `robotcontrol.cpp`:

| Metric | Limit |
|---|---|
| Mean gyro magnitude per axis | < **5 °/s** |
| Sample standard deviation per axis | < **3 °/s** (this is the motion detector) |

**How to hold the robot during calibration:**

The shortest version — **lay the robot on its side on a hard, level surface and don't touch it.** That's it.

Why on its side, not held in your hand?
- Hand tremor easily produces > 3 °/s of jitter, even when you think you're holding still — and the code reads that as motion, then retries until it fails.
- A hard surface (desk, tile, hardwood) couples the IMU to the room; the calibration window sees a true zero.
- Carpet or foam pads partially work but aren't ideal — motor weight makes the chassis settle, and even small settling looks like motion to the gyro.

What's happening on stdout:

```
Calibrating gyro bias (attempt 1/3) - keep the robot still...
Gyro bias OK: X= 0.012  Y= -0.034  Z= 0.008 °/s
```

If you see `⚠ motion detected during calibration` instead, the code automatically retries. Two more failures and it gives up, keeps the previous bias (or zeros, on a fresh install), and logs:

```
✗ Calibration FAILED after 3 attempts. Robot may not balance properly.
   Place the robot flat on a hard surface and restart.
```

**The good news — it's a one-time event per session.** Once calibration succeeds, the bias values are persisted to a separate `bias.ini` file next to `BalanceRobotPI`, so even if a subsequent start-up fails calibration (someone bumps the table) the loaded values are still usable.

**When you should force a fresh calibration:**
- You re-seated the MPU6050 breakout on the chassis
- You swapped in a different MPU6050 board
- The robot was stored in very different temperature than usual (gyro bias has a thermal drift coefficient)
- The bias log lines look way off (e.g. `X= 4.2 °/s` instead of `X= 0.05 °/s`)

To force a re-calibration: stop the app, `sudo rm bias.ini` from the `BalanceRobotPI` directory, restart.

### 6. iOS pairing

On the iPhone, in the iOS app:

1. Open the **Control** tab
2. Tap **Connect**
3. The scanner should pick up a device called **`BalanceRobot`**
4. Tap it — within ~2 seconds you should see `Connected` and the robot's IP appear underneath

If you don't see `BalanceRobot` in the list:
- iOS Bluetooth is off — toggle it
- The Pi isn't advertising — recheck step 2 above
- The Pi was paired before and is now using a different MAC — open iOS Settings → Bluetooth, forget the old entry, retry

Once connected, the iOS app pulls the current parameters from the Pi and populates the Settings tab. If the sliders all read `0`, the parameter read didn't complete — disconnect, reconnect.

## First calibration

Now reconnect the motors (driver screw terminals: M1 = right, M2 = left) and reattach the LiPo (switch #8 ON). The robot is still on a stand or held by hand — don't let it fall over yet.

### A. Encoder direction sanity check

The Speed PID needs encoders that *count up when the wheel rolls forward*. If either wheel's encoder counts the wrong way, the robot will accelerate uncontrollably instead of braking — easy to spot but dangerous to ignore.

With `BalanceRobotPI` running, lift the robot off the stand and **manually roll the right wheel forward** (top of wheel moves toward the front of the robot). Watch the telemetry on the iOS app — the encoder count or velocity for that wheel should go *positive*.

- Goes negative? → set `encoderInvertR=true` in `settings.ini` (or have the iOS app send the right BLE command — depends on the build)
- Same test for the left wheel

This is much safer to do *before* arming the robot.

### B. Mechanical balance point (AC trim)

Power up, then hold the robot perfectly upright by gripping the top deck. Read the **ANGLE** field on the iOS Control tab:

- Reads `0.0° ± 0.5°` → great, your IMU is mounted level, leave `AC = 0`
- Reads e.g. `+1.8°` when you feel the robot is upright → the IMU sits slightly tilted (or the chassis itself does); compensate by setting `AC = -1.8°` from the Settings tab
- The trim is in degrees, signed; positive = front of robot is biased forward

After tuning AC, the robot should feel "neutral" when held upright — releasing it should let it fall in any direction with equal probability, not consistently toward one side.

### C. First armed run

Now the moment of truth:

1. Hold the robot upright, on the floor (carpet is more forgiving than tile)
2. Make sure `Auto-arm` is **ON** in the iOS Settings tab
3. The instant the IMU sees the upright pose, the motors should jump to life and try to hold the position
4. **Slowly** release your grip — fingers ready to catch
5. If it stays up for more than ~2 seconds, you've made it past the hardest part

If it falls immediately:
- Watch which way it falls. **Always the same direction** → AC trim is off, tweak it.
- Both directions, ~50/50 → Kp is too low, raise from 25 to 30
- High-frequency vibration before falling → Kp is too high, lower to 20

If it stays up but drifts in one direction:
- That's normal until Speed PID is tuned — see **Tuning guide** above
- Or your floor isn't level — try a different room

### D. Joystick test

With the robot balancing (or held in your hand):
- Push the joystick gently forward → the robot should *lean forward* and start rolling
- Release → it should *lean back* to brake itself to a stop (this is the Speed PID doing its job)
- If pushing forward makes it lean *backward* → joystick polarity is inverted, set `invertY = true` in `ControlViewController.swift:41`

## Troubleshooting

Common symptoms grouped by what's failing, with most likely cause first.

### Build / install

| Symptom | Likely cause | Fix |
|---|---|---|
| `qmake6: command not found` | Qt6 not installed | `sudo apt-get install qmake6 qt6-base-dev qt6-connectivity-dev` |
| `wiringPi.h: No such file or directory` | WiringPi not built | Clone from `github.com/WiringPi/WiringPi`, `sudo ./build` |
| `i2c/smbus.h: No such file or directory` | `libi2c-dev` missing | `sudo apt-get install libi2c-dev` |
| `cannot find -lwiringPi` at link time | WiringPi built but `ldconfig` cache stale | `sudo ldconfig`, retry |
| Build OK but `BalanceRobotPI` won't start: *"wiringPiSetupPhys failed"* | Ran without `sudo` | Use `sudo ./BalanceRobotPI` |

### Hardware / first power-up

| Symptom | Likely cause | Fix |
|---|---|---|
| Pi won't boot when LiPo is connected, USB-C unplugged | Driver power switch (#8) is OFF | Set it to ON |
| No I²C devices in `i2cdetect` | I²C not enabled in raspi-config | Enable + reboot |
| `0x68` shows but reads garbage | SDA/SCL swapped, or weak pull-ups | Check header pins 3/5; the MPU6050 breakout has its own pull-ups, but bad jumper wires defeat them |
| Motors hum but don't move | Driver VIN voltage too low (LiPo flat) | Check VIN with multimeter, charge pack |
| One motor spins, the other doesn't | Loose screw terminal, or motor M1/M2 swapped | Re-seat both pairs of motor leads in the driver |
| Motor spins, but the wrong direction | Driver output A/B swapped, *or* encoder direction inverted | Easier fix in software: `encoderInvertL/R` |

### BLE

| Symptom | Likely cause | Fix |
|---|---|---|
| iOS app doesn't see `BalanceRobot` in scanner | Pi BLE not advertising | `sudo systemctl restart bluetooth`, restart `BalanceRobotPI` |
| Connects but sliders all read 0 | Parameter read raced the connection event | Disconnect, reconnect once |
| Connects then drops within 1–2 seconds | Pi went to sleep or BlueZ crashed | Check `journalctl -u bluetooth -n 50`; disable Wi-Fi power save: `sudo iwconfig wlan0 power off` |
| Telemetry frozen (always same values) | BalanceRobotPI process died but BLE stayed up | `ps aux \| grep Balance` — restart if it's gone |

### Balance behaviour

| Symptom | Likely cause | Fix |
|---|---|---|
| Always falls in the same direction the instant you let go | AC trim off, or IMU tilted | Adjust `AC` to compensate |
| Both directions, falls in <1 second | Kp too low | Raise to 30–35 |
| High-frequency vibration, then falls | Kp too high | Lower Kp; if still vibrating, raise Kd to 0.15 |
| Balances but drifts steadily forward / backward | Speed PID integral not catching up | Raise Speed Ki (0.20 → 0.30) |
| Balances but oscillates back and forth slowly | Speed Kp too high | Lower to 0.10 |
| Long coast after stick release before braking | Speed Ki too low | Raise to 0.25–0.30 |
| Twitches violently the moment Auto-arm fires | IMU still settling (calibration period missed) | Hold robot perfectly still for 3 seconds before raising upright |
| Balance steadily drifts in pitch even when sitting still | Gyro bias calibration was bad (e.g. robot moved during the 2 s window) | Stop the app, `sudo rm bias.ini`, lay the robot on its side on a hard surface, restart |
| Disarms randomly mid-run | Fall detector triggered by sharp transient | Check that IMU isn't loose; reduce `Kd` if vibration is the trigger |
| Wheels slip and robot can't catch its balance back | Slippery floor / worn tyre rubber | Different surface, or fresh tyres |

### Camera streaming

| Symptom | Likely cause | Fix |
|---|---|---|
| `webcam-stream` shows `activating (auto-restart)` | GStreamer pipeline failed | `journalctl -u webcam-stream -n 50` — usually wrong resolution or camera unplugged |
| Stream URL opens in VLC but no image | Camera initialised but pipeline negotiating | Wait 3–5 s; if still black, check `v4l2-ctl --list-formats-ext` matches the pipeline caps |
| Stream works, but balance robot now jitters | Software H.264 encoder is starving the PID loop | Lower video to 640×480, or `sudo systemctl stop webcam-stream` during tuning |
| `Connection refused` on port 8554 | MediaMTX not running | `sudo systemctl status mediamtx`; restart if dead |

## Known limits

- Below ~9.5 V on the 3S pack (≈3.17 V/cell), PWM saturates during hard corrections and balancing degrades — land and swap packs
- On slippery floors, wheel slip causes encoder velocity to lie
- Very fast maneuvers can saturate the IMU rate gyro

## License

MIT.

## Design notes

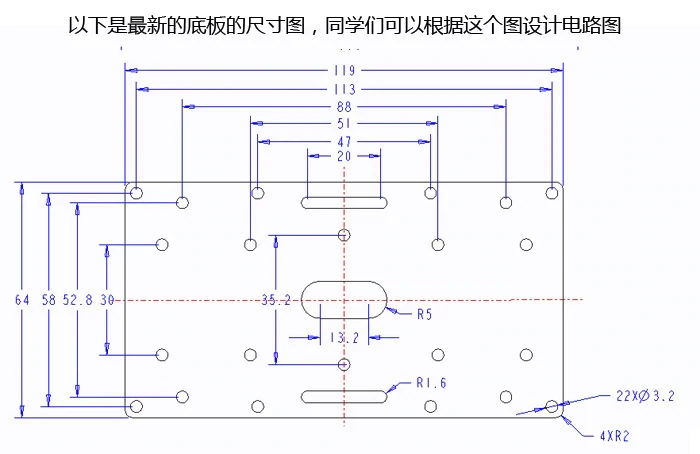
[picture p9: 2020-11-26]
ProjectFiles/chassis.webp

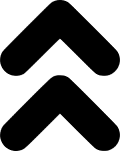
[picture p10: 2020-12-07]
BalanceRobotRemote_IOS/RobotControlBLE/Images/forward.png

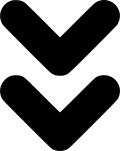
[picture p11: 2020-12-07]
BalanceRobotRemote_IOS/RobotControlBLE/Images/backward.png

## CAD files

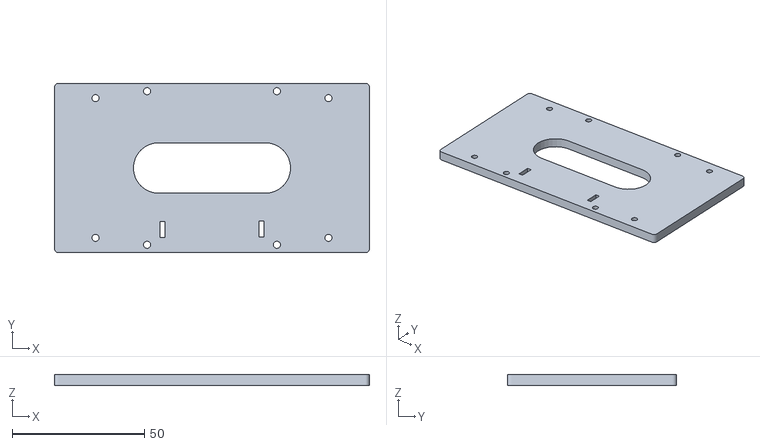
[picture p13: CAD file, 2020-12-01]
ProjectFiles/Robot_chasis_top.stl
119.0 x 64.0 x 4.00

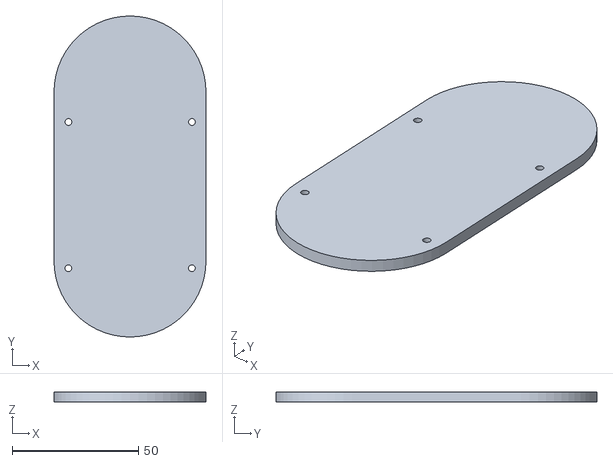
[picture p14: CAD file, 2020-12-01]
ProjectFiles/Robot_safe_top.stl
60.3 x 127.4 x 4.00

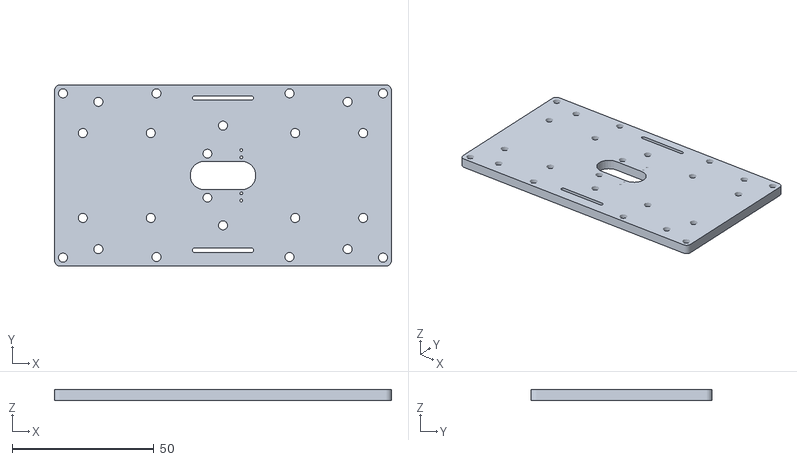
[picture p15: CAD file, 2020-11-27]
ProjectFiles/Robot_chasis_bottom.stl
119.0 x 64.0 x 4.00

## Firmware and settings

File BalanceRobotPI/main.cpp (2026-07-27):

#include <QCoreApplication>
#include <balancerobot.h>
#include <csignal>

// BLE GATT (telefon) ile A2DP ses (JBL) aynı hci0 çipini paylaşınca Qt'nin
// BLE katmanı ses paketlerini görüp "HCI ACL packet data size ..." uyarısı
// basar. Zararsızdır ama müzik/TTS çalarken logu doldurur - SADECE bu mesajı
// filtrele, diğer tüm uyarılar aynen akmaya devam etsin.
static QtMessageHandler g_defaultHandler = nullptr;
static void filteredMessageHandler(QtMsgType type,
                                   const QMessageLogContext &ctx,
                                   const QString &msg)
{
    if (msg.contains(QLatin1String("HCI ACL packet data size")))
        return;
    if (g_defaultHandler)
        g_defaultHandler(type, ctx, msg);
}

// SIGTERM / SIGINT (Ctrl+C) handler — politely ask Qt to exit so destructors
// run, motors stop, and settings.ini gets flushed to disk.
static void signalHandler(int /*sig*/)
{
    QCoreApplication::quit();
}

int main(int argc, char *argv[])
{
    QCoreApplication app(argc, argv);
    g_defaultHandler = qInstallMessageHandler(filteredMessageHandler);

    std::signal(SIGINT,  signalHandler);
    std::signal(SIGTERM, signalHandler);

    BalanceRobot robot;
    return app.exec();
}

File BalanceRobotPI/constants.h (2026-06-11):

#ifndef CONSTANTS_H
#define CONSTANTS_H

#include <QString>
#include <QDebug>
#include <QObject>
#include <QSettings>
#include <QNetworkInterface>
#include <iostream>
#include <deque>
#include <vector>
#include <math.h>
#include <message.h>
#include <sys/time.h>

// -----------------------------------------------------------------------------
// Loop timing
// -----------------------------------------------------------------------------
#define SLEEP_PERIOD 1000   // microseconds — main loop pacing
#define SERIAL_TIME  100    // milliseconds — telemetry / BLE rate
#define SAMPLE_TIME  1      // milliseconds — IMU sample interval

// -----------------------------------------------------------------------------
// I²C
// -----------------------------------------------------------------------------
#define MPU6050_I2C_ADDRESS 0x68
#define RESTRICT_PITCH                // MPU6050 fusion mode flag

// -----------------------------------------------------------------------------
// Motor driver pins — Waveshare RPi Motor Driver Board (MC33886 × 2)
//
// Pin numbers are PHYSICAL header positions (the code calls
// wiringPiSetupPhys()). The driver mounts as a HAT, so these pins mate
// through the 40-pin header, not as loose wires.
//
// Each motor needs 3 lines: IN1 + IN2 (direction) + ENA (PWM enable).
// -----------------------------------------------------------------------------
#define PWMR1  31    // Right motor — IN1 (direction bit 1)
#define PWMR2  33    // Right motor — IN2 (direction bit 2)
#define PWMR   32    // Right motor — ENA (PWM speed,  softPwm 0..255)
#define PWML1  38    // Left  motor — IN1 (direction bit 1)
#define PWML2  40    // Left  motor — IN2 (direction bit 2)
#define PWML   37    // Left  motor — ENA (PWM speed,  softPwm 0..255)

// -----------------------------------------------------------------------------
// Quadrature encoder pins — Hall encoder on each 37 mm DC motor
//
// Channel A (SPD_INT_*) triggers an ISR on rising edge; the ISR then reads
// channel B (SPD_PUL_*) to recover direction. All four inputs use internal
// pull-ups (PUD_UP).
// -----------------------------------------------------------------------------
#define SPD_INT_L 16    // Left  motor encoder — channel A (interrupt)
#define SPD_PUL_L 12    // Left  motor encoder — channel B (direction sample)
#define SPD_INT_R 18    // Right motor encoder — channel A (interrupt)
#define SPD_PUL_R 22    // Right motor encoder — channel B (direction sample)

using namespace std;

// -----------------------------------------------------------------------------
// Language flag for the on-board TTS (Speaker class wraps espeak)
// -----------------------------------------------------------------------------
enum SType
{
    TR,
    EN
};

// -----------------------------------------------------------------------------
// Run a shell command and discard its output. Used by a few helpers that
// need to invoke aplay / amixer / espeak.
// -----------------------------------------------------------------------------
static void execCommand(char* cmd)
{
    char appended[512];
    snprintf(appended, sizeof(appended), "%s >>/dev/null 2>>/dev/null", cmd);
    char buffer[128];
    FILE* pipe = popen(appended, "r");
    if (!pipe) throw std::runtime_error("popen() failed!");
    try {
        while (!feof(pipe)) {
            if (fgets(buffer, 128, pipe) == nullptr) break;
        }
    } catch (...) {
        pclose(pipe);
        throw;
    }
    pclose(pipe);
}
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

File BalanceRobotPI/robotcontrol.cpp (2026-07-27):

#include "robotcontrol.h"
#include <cmath>
#include <algorithm>
#include <vector>
#include <chrono>
#include <unistd.h>
#include <sys/time.h>

RobotControl *RobotControl::theInstance_ = nullptr;

RobotControl* RobotControl::getInstance()
{
    if (theInstance_ == nullptr)
        theInstance_ = new RobotControl();
    return theInstance_;
}

RobotControl::RobotControl(QObject *parent) : QThread(parent)
{
    m_sSettingsFile = QCoreApplication::applicationDirPath() + "/settings.ini";
    m_sBiasFile     = QCoreApplication::applicationDirPath() + "/imu_bias.ini";

    if (QFile(m_sSettingsFile).exists()) {
        loadSettings();
    } else {
        saveSettings();
    }

    if (!initwiringPi()) {
        qDebug() << "WiringPi init failed";
        return;
    }
    if (!initGyroMeter()) {
        qDebug() << "MPU init failed";
        return;
    }

    // Gyro bias kalibrasyonu — robot tamamen hareketsiz olmalı.
    calibrateGyroBias();

    // İlk açıyı accel'den al
    readImu();
    float initAngle = std::atan2((float)ay_, (float)az_) * RAD_TO_DEG;
    currentAngle_ = initAngle;
    kalman.setAngle(initAngle);

    // Pitch PID
    anglePid.setOutputLimit((float)PWM_LIMIT);
    // 0.3° deadband — small wobble around vertical doesn't get amplified.
    // Mechanical play in the wheels means anything tighter creates motor chatter.
    anglePid.setDeadband(0.3f);
    // Tighter derivative low-pass: 0.10 instead of 0.15 smooths more
    // high-frequency gyro noise that was driving the back-and-forth oscillation.
    anglePid.setDerivativeFilter(0.10f);
    // Integral output cap: stop wind-up at ±50 PWM. The I-term is there to
    // compensate steady-state bias (CG offset, motor mismatch), not to
    // dominate the control loop. Without this cap, Ki=0.8 was creating
    // ~1 Hz oscillations as integral built up, overshot, and unwound.
    anglePid.setIntegralOutputCap(50.0f);
    anglePid.setSetpoint(0.0f);

    // Yaw PID — gyro Z hızı sıfırda tutulur, çıkış motor diferansiyeli.
    // Sıkı sınırlarla başla: yaw, pitch dengesini bozmamalı.
    yawPid.setOutputLimit(25.0f);     // ±25 PWM yeterli, denge bozulmaz
    yawPid.setDeadband(5.0f);         // küçük gürültü dikkate alınmasın (°/s)
    yawPid.setDerivativeFilter(0.20f);
    yawPid.setSetpoint(0.0f);
    qDebug() << "RobotControl ready. Kp=" << aggKp << "Ki=" << aggKi
             << "Kd=" << aggKd << " trim=" << aggAC
             << " bias=" << gyroBiasX_ << gyroBiasZ_;
}

RobotControl::~RobotControl()
{
    m_stop = true;
    wait(500);
    stopMotors();
    // Make sure any pending settings get persisted even if the user
    // killed the process before the 5-second save interval fired.
    if (saveDirty) {
        saveSettings();
    }
    delete gyroMPU;
}

void RobotControl::loadSettings()
{
    QSettings settings(m_sSettingsFile, QSettings::IniFormat);
    // Defaults below are the values found most stable after extensive
    // bench testing with the encoder-based position hold enabled.
    //   Kp=25, Ki=40 (UI scale → real Ki=0.4), Kd=0.10
    // Defaults: Twiddle auto-tune sonucu (gerçek donanımda, push-recovery
    // maliyeti 166 -> 44). aggKi UI ölçeğidir (gerçek Ki = aggKi*0.01).
    // Defaults: manevralı PID öğrenmenin (drive/brake/turn) bulduğu set
    // (cost 43.8 -> 30.7; canlı sürüş varsayılanları üzerinde eğitildi).
    aggKp     = settings.value("aggKp",     32.7f).toFloat();
    aggKi     = settings.value("aggKi",     83.0f).toFloat();   // UI ölçeği (gerçek 0.83)
    aggKd     = settings.value("aggKd",      0.138f).toFloat();
    // Varsayılan 0°: trim şasiden şasiye değişir, nötr başlangıç doğrusu.
    // Kullanıcının slider'dan bulduğu değer settings.ini'ye kaydedilir ve
    // her zaman önceliklidir (bu robotta kayıtlı değer: -5).
    aggAC     = settings.value("angleCorrection", 0.0f).toFloat();
    trimFine  = settings.value("trimFine",   0.0f).toFloat();
    autoZeroIntegral = settings.value("autoZero", 0.0f).toFloat();

    pidInvert_      = settings.value("pidInvert",      true).toBool();
    motorInvertL_   = settings.value("motorInvertL",   false).toBool();
    motorInvertR_   = settings.value("motorInvertR",   false).toBool();
    encoderInvertL_ = settings.value("encoderInvertL", true).toBool();
    encoderInvertR_ = settings.value("encoderInvertR", true).toBool();

    // Speed PID — B-Robot tarzı cascade. Defaults bench testing'den.
    // Defaults: donanımda doğrulanmış canlı sürüş seti (DRIVE teşhisiyle
    // bulundu): anlık tepki için Kp yüksek, hızlı dolum için Ki yüksek,
    // hız tavanı 5, eğim yetkisi 7° (entegral tavanı da buna bağlı).
    spdKp      = settings.value("spdKp",      0.25f).toFloat();
    spdKi      = settings.value("spdKi",      0.45f).toFloat();
    spdMaxTilt = settings.value("spdMaxTilt", 7.0f).toFloat();
    spdMaxVel  = settings.value("spdMaxVel",  5.0f).toFloat();
    spdTiltSlew = settings.value("spdTiltSlew", 0.04f).toFloat();
    learnMoveCmd_ = settings.value("learnMoveCmd", 60).toInt();
    learnTurnCmd_ = settings.value("learnTurnCmd", 20).toInt();

    // Legacy fields no longer read or written:
    //   aggSD       (was yaw PID gain for gyro-Z control; now encoder-based
    //               with hardcoded gains)
    //   yawInvert   (was sign for gyro-Z yaw; encoder yaw uses its own sign)

    QSettings bias(m_sBiasFile, QSettings::IniFormat);
    gyroBiasX_ = bias.value("gx", 0.0f).toFloat();
    gyroBiasY_ = bias.value("gy", 0.0f).toFloat();
    gyroBiasZ_ = bias.value("gz", 0.0f).toFloat();
}

void RobotControl::saveSettings()
{
    QSettings settings(m_sSettingsFile, QSettings::IniFormat);
    settings.setValue("aggKp",           aggKp);
    settings.setValue("aggKi",           aggKi);
    settings.setValue("aggKd",           aggKd);
    settings.setValue("angleCorrection", aggAC);
    settings.setValue("trimFine",        trimFine);
    settings.setValue("autoZero",        autoZeroIntegral);
    settings.setValue("pidInvert",       pidInvert_);
    settings.setValue("motorInvertL",    motorInvertL_);
    settings.setValue("motorInvertR",    motorInvertR_);
    settings.setValue("encoderInvertL",  encoderInvertL_);
    settings.setValue("encoderInvertR",  encoderInvertR_);
    settings.setValue("spdKp",           spdKp);
    settings.setValue("spdKi",           spdKi);
    settings.setValue("spdMaxTilt",      spdMaxTilt);
    settings.setValue("spdMaxVel",       spdMaxVel);
    settings.setValue("spdTiltSlew",     spdTiltSlew);
    settings.setValue("learnMoveCmd",    learnMoveCmd_);
    settings.setValue("learnTurnCmd",    learnTurnCmd_);
    // Migrate old key names: if present from older builds, drop them.
    if (settings.contains("aggSD"))     settings.remove("aggSD");
    if (settings.contains("yawInvert")) settings.remove("yawInvert");
    settings.sync();
    saveDirty = false;
}
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

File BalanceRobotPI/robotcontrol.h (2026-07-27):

#ifndef ROBOTCONTROL_H
#define ROBOTCONTROL_H

#include <QCoreApplication>
#include <QFile>
#include <QThread>
#include <QSettings>
#include <QString>
#include "pid.h"
#include "pidautotuner.h"
#include "constants.h"
#include "i2cdev.h"
#include "mpu6050.h"
#include "kalman.h"
#include <softPwm.h>
#include <wiringPi.h>
#include <mutex>
#include <atomic>

// -----------------------------------------------------------------------------
// RobotControl — encoder'sız, sadece IMU tabanlı denge robotu kontrolcüsü.
//
// İki kontrol döngüsü:
//   1) Pitch PID  : gyro X + accel kombinasyonu (Kalman) ile açı kestirimi,
//                   açı hatası → ortak motor PWM çıkışı.
//   2) Yaw  PID   : gyro Z ham hızı, hedef = 0 °/s,
//                   çıkış → sol/sağ motor diferansiyeli.
//                   Mekanik dengesizliği telafi eder, robot doğru yönü tutar.
//
// Encoder donanımı ve velocity/position-hold mantığı kasıtlı olarak yok.
// -----------------------------------------------------------------------------

class RobotControl : public QThread {
    Q_OBJECT

public:
    explicit RobotControl(QObject *parent = nullptr);
    ~RobotControl();
    static RobotControl* getInstance();

    bool initGyroMeter();
    bool initwiringPi();

    void stop();

    void loadSettings();
    void saveSettings();

    // Pitch PID kazançları (iç halka - denge)
    float getAggKp() const { return aggKp; }
    void  setAggKp(float v) { aggKp = v; saveDirty = true; }
    float getAggKi() const { return aggKi; }
    void  setAggKi(float v) { aggKi = v; saveDirty = true; }
    float getAggKd() const { return aggKd; }
    void  setAggKd(float v) { aggKd = v; saveDirty = true; }

    // AC = "angle correction" = ana trim (UI slider 0..25.5°)
    float getAggAC() const { return aggAC; }
    void  setAggAC(float v) { aggAC = v; saveDirty = true; }

    // SD slider artık yaw PID Kp olarak yeniden tanımlandı.
    // UI uyumluluğu için aynı slot kullanılıyor.
    float getAggSD() const { return aggSD; }
    void  setAggSD(float v) { aggSD = v; saveDirty = true; }

    // Speed PID parametreleri (B-Robot benzeri cascade için)
    float getSpdKp() const { return spdKp; }
    void  setSpdKp(float v) { spdKp = v; saveDirty = true; }
    float getSpdKi() const { return spdKi; }
    void  setSpdKi(float v) { spdKi = v; saveDirty = true; }
    float getSpdMaxTilt() const { return spdMaxTilt; }
    void  setSpdMaxTilt(float v) { spdMaxTilt = v; saveDirty = true; }
    float getSpdTiltSlew() const { return spdTiltSlew; }
    void  setSpdTiltSlew(float v) { spdTiltSlew = v; saveDirty = true; }
    // Geçici hız tavanı (sesli komut için). 0 = kapalı, spdMaxVel geçerli.
    // Kalıcı DEĞİLDİR: settings.ini'ye yazılmaz, joystick ayarına dokunmaz.
    void  setTempMaxVel(float v) { tempMaxVel_.store(v); }
    float getSpdMaxVel() const { return spdMaxVel; }
    void  setSpdMaxVel(float v) { spdMaxVel = v; saveDirty = true; }

    // Komutlu hareket (BLE'den)
    std::atomic<int> needSpeed{0};
    std::atomic<int> needTurnL{0};
    std::atomic<int> needTurnR{0};
    int  getNeedSpeed() const { return needSpeed.load(); }
    void setNeedSpeed(int v) { needSpeed.store(v); }
    int  getNeedTurnL() const { return needTurnL.load(); }
    void setNeedTurnL(int v) { needTurnL.store(v); }
    int  getNeedTurnR() const { return needTurnR.load(); }
    void setNeedTurnR(int v) { needTurnR.store(v); }

    // Arm/disarm
    bool getIsArmed() const { return isArmed.load(); }
    void setIsArmed(bool armed);

    // Auto mode (oto-arm + oto-recovery)
    bool getAutoMode() const { return autoMode.load(); }
    void setAutoMode(bool on) { autoMode.store(on); }

    // Yaw kilidi (otomatik doğrultu tutma) — varsayılan açık.
    // UI'da position-hold yerine yaw-hold olarak işlev görür.
    bool getPositionHold() const { return yawLock.load(); }
    void setPositionHold(bool on) { yawLock.store(on); }

    // Hassas trim (signed, °)
    float getTrimFine() const { return trimFine; }
    void  setTrimFine(float v) { trimFine = v; saveDirty = true; }

    void resetTrim();

    // PID öğrenme modu (mobil taraftan mPidLearn ile tetiklenir).
    // Gerçek iş kontrol döngüsü thread'inde yapılır; buradaki çağrılar
    // sadece atomik istek bayrakları set eder.
    bool startPidLearning();   // false = reddedildi (dengede değil)
    int  getLearnMoveCmd() const { return learnMoveCmd_; }
    int  getLearnTurnCmd() const { return learnTurnCmd_; }
    void setLearnMoveCmd(int v) { learnMoveCmd_ = std::clamp(v, 20, 160); saveDirty = true; }
    void setLearnTurnCmd(int v) { learnTurnCmd_ = std::clamp(v, 10, 50);  saveDirty = true; }
    void stopPidLearning();
    bool isPidLearning() const { return pidTuner_.isActive(); }
    QString takePidLearnStatus() { return pidTuner_.takeStatus(); }

    // Telemetri (BLE üzerinden)
    struct Telemetry {
        float angle;        // °  - pitch
        float gyroRate;     // °/s - pitch rate
        float yawRate;      // °/s - yaw rate (sapma)
        float targetAngle;  // °
        float trim;         // °
        int   pwmL;
        int   pwmR;
        bool  armed;
        bool  fallen;
        bool  autoMode;
        bool  positionHold;  // -> yaw lock state
        bool  pidLearning;   // PID öğrenme modu aktif mi
    };
    Telemetry getTelemetry();
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

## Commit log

2019-01-18 Speak and thread
    Speak and thread fixed
    [balancerobot.cpp]
2019-02-24 fix pid
    fix pid
    [balancerobot.cpp, main.cpp, message.cpp]
2019-03-17 pid
    pid
2019-03-19 sound fix
    sound fix
    [balancerobot.cpp]
2019-03-20 pid fix
    pid fix
    [balancerobot.cpp, main.cpp, mpu6050.cpp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]
2019-03-21 pid adaptive
    pid adaptive
2019-04-04 IOS remote
    IOS remote
    [chasis_with_mpu6050.stl, robot_chasis.stl]
2019-04-04 pid settings
    pid settings
2020-07-08 i2c
    i2c
2020-07-09 start fix
    start fix
    [balancerobot.cpp]
2020-11-25 stl
    stl
    [3.5_robot_chasis.stl]
2020-11-25 rasp
    rasp
    [rasp_robot_chasis.3mf, robot_chasis.stl]
2020-11-26 chassis
    chassis
2020-11-27 gcode
    gcode
    [AI3M_robot_chasis_top_for_raspberry.3mf, robot_chasis_bottom.stl]
2020-12-01 fcstd
    fcstd
    [Robot_safe_top_for_raspberry.stl, robot_safe.FCStd, robot_top.FCStd]
2020-12-03 fc
    fc
    [robot_top.FCStd]
